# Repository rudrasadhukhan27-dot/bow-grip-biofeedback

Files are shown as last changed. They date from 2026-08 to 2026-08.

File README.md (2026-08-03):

# Bow-Grip Biofeedback: An Open Wearable for Measuring Violin Bow-Hold Tension


An open-source wearable that continuously measures violin bow-grip force, forearm muscle activation, and bow motion, and can deliver real-time haptic feedback when grip exceeds a personalised threshold. Built around an ESP32 and off-the-shelf sensors for roughly ₹4,000 / ~US$50 in parts.

This repository contains the complete hardware design, firmware, logging software, experimental protocol, pre-registration, analysis code, and results of a 33-session single-subject study conducted with the device.

The wearable in playing position

---

## Why this exists

Excessive bow-hold tension ("overgrip") is a widely discussed contributor to playing-related pain and injury among string players, but it is usually assessed by a teacher's eye rather than measured. This project asks whether it can be measured continuously and unobtrusively during real playing, whether haptic feedback reduces it, and whether it can be predicted before it occurs.

The study answers the first question clearly, the second one negatively, and the third one partially. All three results are reported here.

---

## Key findings (summary)

Across 33 playing sessions by a single violinist, in a pre-registered A-B-A-B reversal design with a transfer test:

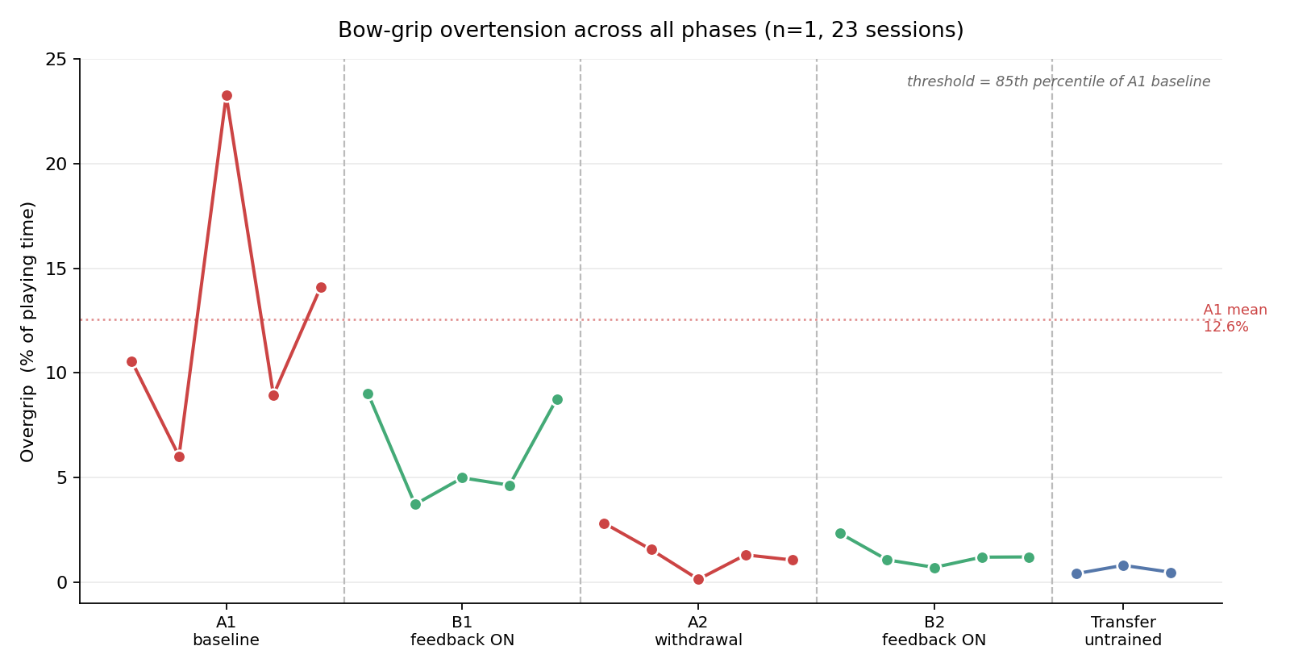
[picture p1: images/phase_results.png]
Overgrip across all phases


| Phase | Haptic feedback | Overgrip (% of playing time) |
|---|---|---|
| A1 baseline | off | **12.6%** |
| B1 intervention | on | 6.2% |
| A2 withdrawal | off | 1.4% |
| B2 re-intervention | on | 1.3% |
| Transfer (untrained repertoire) | off | **0.6%** |

**1. Overgrip fell by roughly 95% and stayed down.** Baseline versus withdrawal, re-intervention, and transfer all show complete non-overlap (NAP = 100%, Tau = +1.00). The reduction persisted with feedback removed and generalised to repertoire the device had never been used with. Note that each phase was recorded within a single day, so these are **descriptive** comparisons across 5 testing days, not inferentially tested replicates — see [`docs/DEVIATIONS.md`](docs/DEVIATIONS.md).

**2. The design did not show that the haptic feedback caused it.** Overgrip declined monotonically with elapsed time (*r* = −0.858, *p* = 1.7 × 10⁻⁷). Adding feedback on/off to the trend model explained nothing (*p* = 0.77), and the first feedback phase was not distinguishable from baseline. A 14-day unmeasured gap between B1 and A2 contains the largest single drop (6.2% → 1.4%). Practice, measurement reactivity, proprioceptive attention from wearing the sensor, and unrecorded activity during that gap are all equally consistent with the data. **This is reported as a null result on the causal question.**

**3. Overgrip onset is weakly predictable.** A gradient-boosted model using leave-one-session-out validation reaches average precision 0.093 at the pre-registered 200–400 ms horizon — about 7× chance and 2× a grip-level baseline (ROC-AUC 0.86). But performance degrades sharply beyond 200 ms, the predictive signal comes almost entirely from grip dynamics rather than bow kinematics, and at a tolerable false-alarm rate (≤2/min) event recall is poor. Practical warning systems are not yet viable from these signals.

Full details in [`RESULTS.md`](RESULTS.md).

---

## Hardware

Electronics in the printed enclosure
EMG electrode placement on the forearm extensors

### Bill of materials

| Component | Notes |
|---|---|
| ESP32-WROOM-DA dev board | Any ESP32 with ADC1 pins available |
| Force-sensitive resistor (FSR) | Mounted at the thumb contact point on the bow |
| BioAmp EXG Pill (Upside Down Labs) | Surface EMG front-end; powered from **3.3 V** |
| MPU-6050 IMU | I²C, address `0x68` |
| ERM coin vibration motor, 3 V, ~10 mm | ~60–100 mA |
| IRLZ44N logic-level MOSFET | Motor driver |
| 1N4007 diode | Flyback across motor |
| Resistors | Gate resistor; FSR voltage divider |
| Gel electrodes (×3) | Disposable, for EMG |
| 3D-printed enclosure | STLs in [`hardware/`](hardware/) |

### Pin map

| Signal | ESP32 pin |
|---|---|
| FSR (thumb) | D35 |
| FSR (second channel, unused) | D34 |
| EMG output (BioAmp) | D32 |
| IMU SDA | D21 |
| IMU SCL | D22 |
| Motor gate (MOSFET) | D25 |

All analog inputs are on ADC1, which remains usable while WiFi/Bluetooth is active.

**Important:** power the BioAmp EXG Pill from the **3.3 V** rail, not 5 V. At a 3.3 V supply its output cannot exceed the ESP32's ADC range, so no level shifting or divider is required.

### Electrode placement

Two signal electrodes (IN+, IN−) on the belly of the forearm **extensor** group — the hairy, dorsal side of the bowing forearm, roughly one third of the way from elbow to wrist — spaced 2–3 cm apart along the muscle fibres. Reference electrode on a bony landmark (olecranon or wrist). Clean the skin with alcohol and mark the positions so placement is repeatable across sessions.

### Enclosure

`hardware/electronics_box_snap.stl` and `electronics_lid_snap.stl`: an 86 × 56 × 29 mm snap-fit case with 26 mm internal depth, a front window with a 3 mm frame, and two side cable slits. Print the lid plate-down for a support-free surface. Snap engagement is 0.8 mm — reduce to 0.5 mm if your printer runs tight or you print in brittle PLA.

---

## Firmware

[`firmware/logger_firmware.ino`](firmware/) samples all channels on a fixed schedule and streams CSV over USB serial at 115200 baud.

```
t_ms,fsr1,fsr2,emg,ax,ay,az,gx,gy,gz,mode
```

Two modes, switched by sending a single character over serial:

- `R` — **record**: motor disabled. Used for all baseline, withdrawal, and transfer sessions.
- `F` — **feedback**: motor driven by a two-zone ramp above the grip threshold.

The feedback curve is defined by `GRIP_THRESH` and `ZONE2_START`. **These must be derived from the individual's own baseline data, not copied from this repository.** In this study they were set to the 85th and 95th percentiles of the participant's pooled A1 grip distribution (1301 and 1584 in raw ADC units).

Dependencies: `Wire`, [`MPU6050_tockn`](https://github.com/tockn/MPU6050_tockn). The tockn library is used because many inexpensive MPU-6050 modules are clones that fail to initialise with Adafruit's driver. Note that it reports acceleration in **g**, not m/s².

The firmware targets 100 Hz. Achieved rates ranged from 21 Hz to 100 Hz depending on I²C timing; the effective rate is recoverable per session from the `t_ms` column and should be reported rather than assumed.

ESP32 Arduino core 3.x is required — the code uses `ledcAttach(pin, freq, res)` and pin-addressed `ledcWrite`, which replaced the older `ledcSetup`/`ledcAttachPin` API.

---

## Logging software

[`software/logger.py`](software/) reads the serial stream and writes one CSV per session, validating every row and reporting a live corruption rate.

```bash
pip install pyserial

# baseline / withdrawal / transfer session (motor off)
python3 logger.py S1_A1_s01.csv

# feedback session (motor on)
python3 logger.py S1_B1_s01.csv --mode F
```

Rows are rejected unless they contain exactly 11 fields with correctly typed values and a mode flag of exactly `R` or `F`. This matters: at 230400 baud this build produced intermittently garbled rows, with the mode column bleeding into adjacent values. Dropping to 115200 eliminated the corruption (0.00% rejection in all subsequent sessions), and strict validation catches anything that still slips through.

---

## Experimental protocol

[`docs/data_collection_protocol.md`](docs/) contains the full session procedure. In brief, each session ran:

1. Fixed warm-up (before logging)
2. 3 × 5 s maximum voluntary contractions (MVC), for per-session EMG normalisation
3. 30 s rest baseline holding the instrument
4. 3 × maximum grip presses (pre)
5. ~8 minutes of fixed repertoire — A minor harmonic and D major, three octaves, cycled continuously at fixed tempo and dynamic
6. 3 × maximum grip presses (post)
7. Borg CR-10 and 0–10 discomfort ratings

Held constant across all sessions: repertoire, tempo, dynamic level, time of day, warm-up, electrode positions, sensor mounting, **and bow**. Dynamic level matters particularly — if loudness varies, force spikes required by the music become indistinguishable from overgrip.

The pre-registration, written and locked before data collection, is in [`docs/pre_registration.md`](docs/).

---

## Analysis

[`analysis/`](analysis/) contains the prediction pipeline:

- `predict.py` — resampling to a uniform 50 Hz grid, IMU-based segmentation of the bowing period, overgrip onset detection, and 21-feature extraction
- `eval.py` — leave-one-session-out validation with event-level recall at a bounded false-alarm rate, plus permutation feature importance
- `lead.py` — the lead-time curve across anticipation horizons

One methodological note worth repeating: the primary outcome is the percentage of **playing** time above threshold. Early analyses that used whole-file data were inflated by the MVC clenches and maximum grip presses, which are deliberate maximal squeezes. The bowing period is segmented from IMU motion before computing the outcome.

---

## Limitations

- **Single subject.** All findings are within-individual. Nothing here establishes generality across violinists.
- **Sessions are clustered by day.** All 33 sessions fall on 7 calendar dates, with each phase run as five consecutive recordings in a single sitting. Sessions within a phase are therefore not independent observations, phase is confounded with date, and the reported effect-size statistics are optimistic. See `RESULTS.md` §8.
- **Practice and intervention are confounded.** The reversal design failed to isolate the feedback; see finding 2 above.
- **Phase is confounded with day, and sessions are pseudo-replicated.** All sessions in a phase were recorded in one afternoon minutes apart, giving 5 testing days rather than 23 independent sessions. Inferential statistics on phase comparisons are not appropriate; the comparisons are descriptive.
- **A 14-day unmeasured interval** sits between B1 and A2, spanning the largest observed change.
- **Subjective secondary outcomes were not collected.** Borg CR-10 and discomfort ratings were pre-registered but never recorded, and no session log was kept.
- **Floor censoring.** The FSR cannot distinguish very light contact from no contact — both read zero. As grip lightened over the study, an increasing share of playing fell below the sensor's activation floor (up to 57% of samples in the final session). This does not affect the overgrip metric, which counts samples above a high threshold, but median and mean grip in later sessions should be read as directional only. A fresh-sensor comparison confirmed the original FSR's low-force sensitivity had **not** degraded, ruling out sensor wear as the explanation.
- **EMG is not comparable across an electrode-setup change** partway through the study. Activation declined within each setup era, but absolute levels either side of the boundary cannot be compared.
- **One discarded run.** Five sessions were invalidated by using a different bow, which altered thumb contact geometry enough to change the grip distribution substantially. Those sessions are retained in the trend analysis as practice exposure but excluded from phase comparisons.
- **Threshold provenance.** The overgrip threshold was derived from A1 and held fixed thereafter by design, meaning later phases were scored against an early-study reference.
- **No blinding.** The participant knew which condition each session was in.

---

## What would strengthen this

The single most valuable extension is a three-arm design with additional participants: practice-only (no device), device-worn-but-inert, and device-with-feedback. That would separate motor practice, measurement reactivity, and haptic feedback — the three explanations this study cannot currently distinguish.

---

## Repository structure

```
firmware/     ESP32 Arduino sketches (logging + feedback, bench tests)
software/     Python serial logger
hardware/     Enclosure STLs, pin map, wiring notes
docs/         Pre-registration, deviations, protocol, build guide
analysis/     Prediction pipeline and validation scripts
data/         Session CSVs, incl. excluded runs (see data/README.md)
```

---

## Licence

- Code (`firmware/`, `software/`, `analysis/`): [MIT](LICENSE)
- Hardware designs (`hardware/`): CERN-OHL-P v2
- Documentation, protocol, and results (`docs/`, `README.md`, `RESULTS.md`): CC BY 4.0

---

## Credits

This project builds on the **BioAmp EXG Pill** by [Upside Down Labs](https://github.com/upsidedownlabs), an open-source biopotential front-end. Please observe their licence terms when reusing that portion of the design.

IMU support uses [MPU6050_tockn](https://github.com/tockn/MPU6050_tockn) by tockn.

---

## Citing this work

See [`CITATION.cff`](CITATION.cff), or use the DOI issued by Zenodo for the corresponding release.

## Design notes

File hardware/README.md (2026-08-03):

# Hardware

## Pin map

| Signal | ESP32 pin | Notes |
|---|---|---|
| FSR (thumb) | D35 | Voltage divider to GND; primary grip signal |
| FSR (second) | D34 | Unused in this build |
| EMG output | D32 | BioAmp EXG Pill, powered from **3.3 V** |
| IMU SDA | D21 | MPU-6050 at `0x68` |
| IMU SCL | D22 | |
| Motor gate | D25 | IRLZ44N gate via series resistor |

All analog inputs are on ADC1, which stays usable while the radio is active.

## Notes that cost time to learn

- **Power the BioAmp from 3.3 V, not 5 V.** At a 3.3 V supply its output cannot exceed the ESP32's ADC range, so no divider or level shifter is needed.
- **The motor needs a flyback diode** (1N4007) across its terminals and a logic-level MOSFET. Without the diode, switching spikes couple into everything.
- **Battery feeds VIN**, never the 3V3 pin — the 3V3 pin bypasses the regulator.
- **Many MPU-6050 modules are clones** that fail to initialise with some libraries even when an I²C scan finds them at `0x68`. `MPU6050_tockn` works; note it reports acceleration in g.
- **Sensor placement matters more than sensor count.** A second FSR on the middle finger recorded almost nothing — that finger applies negligible force in a violin bow hold. Thumb and index are the pressure points.
- **The bow is part of the calibration.** Changing to a different bow altered thumb contact geometry enough to shift the grip distribution substantially and invalidated a five-session run. Treat the instrument as a fixed experimental condition.

## Enclosure

`electronics_box_snap.stl` + `electronics_lid_snap.stl` — 86 × 56 × 29 mm snap-fit case, 26 mm internal depth, 2 mm walls, 3 mm floor. Front window with a 3 mm frame; two 18 × 10 mm side slits for cabling, one offset 15 mm toward the front.

Print the lid plate-down (lip upward) for a support-free top surface. Snap engagement is 0.8 mm with 0.3 mm lip clearance per side — reduce engagement to ~0.5 mm if the lid will not seat or if printing in brittle PLA, increase to ~1.0 mm if it is loose.

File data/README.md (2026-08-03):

# Session data

33 playing sessions from a single participant. 23 in this directory were used for phase comparisons; 10 in [`excluded/`](excluded/) were discarded for documented reasons but are published because they still represent real practice exposure and are used in the trend analysis.

## Files

| Pattern | Phase | Feedback | n |
|---|---|---|---|
| `S1_A1_s01–05.csv` | A1 baseline | off | 5 |
| `S1_B1_s01–05.csv` | B1 intervention | on | 5 |
| `S1_A2_s01–05.csv` | A2 withdrawal | off | 5 |
| `S1_B2_s01–05.csv` | B2 re-intervention | on | 5 |
| `S1_TR_s01–03.csv` | Transfer, untrained repertoire | off | 3 |

Transfer sessions used a different piece each: s01 Albinoni *Allegro assai* (bars 1–20, played slower than the other two), s02 Mel Bonis *Allegretto non troppo* (bars 1–20), s03 Florence Price *Elfentanz* (bars 1–38).

### Excluded

| Pattern | Reason |
|---|---|
| `excluded/S1_A2_attempt1_noEMG_s01–05.csv` | EMG electrodes were not applied. Grip data valid; EMG channel meaningless. |
| `excluded/S1_A2_attempt2_differentbow_s01–05.csv` | A different bow altered thumb contact geometry enough to shift the grip distribution. |

Both are retained in the practice-exposure trend analysis. Neither is used for phase comparisons. See [`../docs/DEVIATIONS.md`](../docs/DEVIATIONS.md).

## Columns

| Column | Meaning |
|---|---|
| `wallclock_iso` | **Cleared.** Host timestamps removed before publication; column retained so field positions match the analysis code. |
| `t_ms` | Device millisecond timestamp — use this for all timing |
| `fsr1` | Thumb force, raw ADC 0–4095 |
| `fsr2` | Second FSR channel — not a signal, see below |
| `emg` | BioAmp EXG Pill output, raw ADC 0–4095, DC-centred |
| `ax, ay, az` | Accelerometer, g |
| `gx, gy, gz` | Gyroscope, deg/s |
| `mode` | `R` motor off, `F` feedback active |

## Before you analyse

- **Use `t_ms`, not row index.** Effective sample rate varies: roughly 21–50 Hz for A1 and B1, a stable 100 Hz from A2 onward after a serial baud fix. Recover it per file.
- **Segment the bowing period first.** Each file begins with MVC clenches, a rest baseline, and maximum grip presses — deliberate maximal squeezes that will inflate any whole-file statistic. The published analysis isolates bowing via gyroscope magnitude (2 s rolling mean above 25 °/s, longest contiguous block). See [`../analysis/predict.py`](../analysis/predict.py).
- **`fsr2` is not a signal.** The second sensor sat on the middle finger, which applies negligible force in a violin bow hold. It was removed early on. Grip means thumb contact force.
- **Grip is floor-censored.** Very light contact and no contact both read 0. This affects median and mean grip in later sessions; it does not affect the overgrip metric, which counts samples above 1301.
- **EMG is an amplitude measure**, not a spectral one — the sample rate is far too low for median-frequency fatigue analysis.
- **EMG is not comparable across the electrode re-application** between B1 and A2. Absolute levels shift roughly threefold at that boundary.

## Overgrip threshold

1301 raw ADC — the 85th percentile of the pooled A1 baseline grip distribution (n = 70,025). Derived once from baseline and held fixed for every later phase, as pre-registered.

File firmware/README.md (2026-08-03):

# Firmware

| Sketch | Purpose |
|---|---|
| `logger_firmware.ino` | Main firmware. Streams CSV at 115200 baud; `R`/`F` switches record/feedback. |
| `sensor_check.ino` | Bench test. Verifies FSR, EMG, IMU, and motor; flags common FSR fault signatures. |

## Before collecting data

Run `sensor_check.ino` and confirm:

- **FSR** — steady baseline when untouched, smooth rise when pressed. Values jumping between 0 and 4095 indicate a loose connection or a missing divider resistor, not real force.
- **EMG** — mid-range value that moves when you clench. A flat trace usually means electrode contact, not wiring.
- **IMU** — roughly 1 g total acceleration at rest; gyroscope responds to rotation.
- **Motor** — audible and palpable buzz. Watch for a board brownout when it starts; if the sketch restarts, the motor's current draw is sagging the supply rail.

## Setting the feedback threshold

`GRIP_THRESH` and `ZONE2_START` in `logger_firmware.ino` must come from the wearer's own baseline. Collect the baseline phase with the motor off, pool the grip samples, and take the 85th and 95th percentiles. A guessed threshold either fires constantly or never.

## Requirements

- ESP32 Arduino core **3.x** — the sketches use `ledcAttach(pin, freq, res)` and pin-addressed `ledcWrite`, which replaced `ledcSetup`/`ledcAttachPin`
- [MPU6050_tockn](https://github.com/tockn/MPU6050_tockn)

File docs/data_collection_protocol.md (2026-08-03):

# Data Collection Protocol — Bow-Grip Study (1 + B)

This is the complete, do-it-in-order guide from "device built" to "data ready to analyze." It covers what to collect, how, the exact session steps, the study sequence, and the mistakes that silently ruin a dataset. Everything you need is here, including the logging firmware and laptop logger (the two pieces not yet built).

---

## 0. What you are collecting and why (read once)

**The recorded signal (continuous, every session):** force from both FSRs, EMG from the forearm, and motion from the IMU — all timestamped at 100 Hz. From this one stream you get *both* halves of the project:
- **B (prediction):** can overgrip be forecast ~200–300 ms before it happens, from grip + motion? (analyzed offline later)
- **Option 1 (causation):** does feedback produce a *lasting* drop in overgrip? (proven by the A-B-A-B sequence)

**The single most important rule:** during RECORD sessions the motor is OFF. You collect clean data motor-off; the motor only runs in the FEEDBACK phases. EMG is microvolt-level and the motor pollutes it, so never record clean data with it buzzing.

---

## 1. One-time prerequisites (do all of these before session 1)

### 1.1 Hardware verified
All three sensor types respond (already done): FSR1 (D35), FSR2 (D34), EMG (D32), IMU (0x68 on D21/D22). Motor on D25 buzzes.

### 1.2 Flash the logging firmware
This replaces the test sketch. It samples at 100 Hz, streams CSV over USB serial, and has a RECORD/FEEDBACK mode (motor off vs on). The motor curve bug is fixed here. **Full code in Appendix A.**

### 1.3 Set up the laptop logger
A short Python script reads the serial stream and writes a timestamped CSV file per session. **Full code in Appendix B.** Test it: run it, confirm a CSV fills with rows, open it, check all 10 columns have sensible numbers.

### 1.4 Calibrate the FSRs to real force units (do once)
ADC counts aren't publishable; convert them to grams-force. **Procedure in Appendix C.** Save the calibration curve — you apply it later in analysis, not on the device.

### 1.5 Lock your pre-registration (write it BEFORE collecting)
Decide and write down, and do not change once data starts:
- **Hypothesis** (e.g., "feedback reduces overgrip rate, and the reduction persists when feedback is removed").
- **Primary outcome metric** — pick ONE now. Recommended: **overgrip rate = % of playing time grip exceeds your personal overgrip threshold.** (Alternatives: overgrip events per minute; % of bow changes that are overgrip events.)
- **Overgrip threshold definition** — e.g., grip force above the 85th percentile of your own relaxed-baseline playing, in calibrated grams. Define the rule, not the number (the number comes from baseline data).
- **Phase structure and session counts** (Section 4).
- **Repertoire, tempo, dynamics** held constant (Section 1.6).

### 1.6 Fix the experimental conditions (these stay identical every session)
Variability here masks the effect you're hunting, so nail them down:
- **Repertoire:** the same one or two etudes/scales every session. Pick material with frequent bow changes (where overgrip lives).
- **Tempo:** fixed BPM with a metronome. Same every session.
- **Dynamics:** same dynamic level (e.g., mezzo-forte) throughout. This is critical — it removes the "loud notes legitimately need force" confound, so a force spike means overgrip, not music.
- **Time of day:** same window each day (fatigue and warmth vary across the day).
- **Warm-up:** a fixed, identical warm-up before every recording.
- **Electrode placement template:** mark the electrode spots (photo + measure from a bony landmark) so EMG placement is repeatable. Placement drift changes EMG amplitude between sessions.

### 1.7 Consent/ethics (if anyone other than you participates)
Written informed consent; parental consent for under-18s. Check your school's human-subjects process — required before collecting from others and for competitions like ISEF.

---

## 2. The data you collect (exact contents)

### 2.1 Continuous stream (logged automatically, 100 Hz)
Each CSV row: `wallclock_iso, t_ms, fsr1, fsr2, emg, ax, ay, az, gx, gy, gz, mode`
- `t_ms` device timestamp (keeps all channels aligned — this is your sync).
- `fsr1, fsr2` raw 0–4095 (convert to grams later via calibration).
- `emg` raw 0–4095.
- `ax,ay,az` accel (g), `gx,gy,gz` gyro (deg/s) — bow motion.
- `mode` R or F.

### 2.2 Per-session metadata (write in the session log, Appendix D)
Subject ID, date, **time of day**, **phase** (A1/B1/A2/B2/Transfer), **condition** (motor OFF or ON), repertoire, tempo (BPM), dynamic level, warm-up done (y/n), electrode placement OK (y/n), battery charged (y/n), any anomalies (slips, interruptions, motor accidentally on, etc.), file name.

### 2.3 Per-session calibration recordings (short, every session)
- **MVC (max voluntary contraction):** 3 × 5-second maximum forearm clenches at the start. Used to normalize EMG so it's comparable across sessions (electrode placement varies day to day — without this, EMG amplitudes aren't comparable). Log the file/time markers.
- **Rest baseline:** 30 s of quiet (instrument held, not playing) to capture resting grip/EMG.

### 2.4 Optional secondary outcomes (recommended, low effort)
- **Grip endurance / strength:** squeeze the digital dynamometer (peak-hold) before and after the session; the drop is a fatigue biomarker. (You can drop this once you've validated EMG-based fatigue against it — see Section 6.)
- **Subjective:** Borg CR-10 perceived exertion and a 0–10 forearm discomfort rating, immediately post-session.

---

## 3. Single-session procedure (run this exact sequence every time)

1. **Setup (5 min):** charge confirmed, device on, electrodes placed per template (clean skin first), glove/FSRs on, IMU seated on hand. Start the logger on the laptop with a new filename (Section 7 naming).
2. **Confirm signals (1 min):** wiggle bow → IMU moves; clench → EMG moves; press fingers → FSRs move. Abort and fix if any channel is dead.
3. **MVC recording (1 min):** mode = RECORD. Record 3 × 5 s maximum clenches, ~10 s rest between. Note the times.
4. **Rest baseline (1 min):** hold instrument quietly, 30 s, no playing.
5. **Pre-session measures:** dynamometer max (×3, record peak); note nothing hurts.
6. **Fixed warm-up:** identical every session.
7. **The recording (the data):** mode per the phase (RECORD = motor off for A-phases; FEEDBACK = motor on for B-phases). Play the fixed repertoire at the fixed tempo and dynamic for a fixed duration (e.g., 8–12 min). Keep the logger running the whole time.
8. **Post-session measures:** dynamometer max (×3), Borg CR-10, discomfort rating.
9. **Stop & save:** stop logger, confirm the CSV saved and has rows, back it up immediately (Section 7).
10. **Fill the session log** (Appendix D) completely before you forget.

Keep every session the same length and structure. Your statistical power comes from many comparable sessions, not from any one long one.

---

## 4. The study sequence (the A-B-A-B reversal)

Run phases in order. **Each phase = 5–8 sessions** (minimum 3; 5+ is much safer). Same repertoire/tempo/dynamics throughout all phases.

| Phase | Mode | Motor | Purpose |
|---|---|---|---|
| **A1 baseline** | RECORD | OFF | your natural overgrip rate |
| **B1 intervention** | FEEDBACK | ON | does overgrip drop while feedback is on? |
| **A2 withdrawal** | RECORD | OFF | **the key phase** — does the drop persist with feedback gone? |
| **B2 re-intervention** | FEEDBACK | ON | does the effect return, confirming feedback caused it? |
| **Transfer test** | RECORD | OFF | play *untrained* repertoire — did the improvement carry over? |

**The logic:** a drop in B1 alone proves nothing. A drop that **persists into A2** = learning. A pattern that tracks feedback on/off/on/off across all phases = causal evidence from one subject. The transfer test at the end (music the device never trained on) is what shows the skill actually changed, not just task-specific correction.

**If you have 1–2 other violinists:** run the same sequence on each (they can do fewer sessions). Your own deep run is the spine; they are replication. A busy participant who can only do 1–2 sessions is a "generalization probe," not a full subject — use their data descriptively, don't force it into the reversal.

---

## 5. The prediction (B) data — what to ensure during collection

B is analyzed offline from the same recordings, so you don't do anything special on the device. But make sure the **A1 baseline (motor-off) sessions contain plenty of natural overgrip events** — that's the raw material for training the predictor. Practically: the baseline material should provoke overgrip (frequent bow changes, your normal playing). You need many events across several baseline sessions for the offline model to learn from. Nothing to configure — just don't skimp on baseline sessions.

---

## 6. Validate EMG-based fatigue early (do this in the first 2–3 sessions)

Record both the dynamometer drop and the EMG. Later you'll check offline whether the EMG fatigue signal (its frequency content shifting down over a session) tracks the grip-strength drop. Once they agree, you can rely on EMG alone and stop the per-session dynamometer step. Do this validation early so you're not stuck doing manual grip tests forever.

---

## 7. Data management (do this rigorously — lost/mislabeled data is unrecoverable)

- **File naming:** `S1_A1_s03_2026-07-14.csv` = subject S1, phase A1, session 03, date. Be consistent.
- **One folder per subject;** a master spreadsheet (the session log) with one row per session.
- **Back up after every session** — copy the CSV to a second location (cloud + drive). A corrupted laptop mid-study with no backups ends the project.
- **Never edit raw CSVs.** Do all cleaning in analysis scripts on copies.
- Keep the **MVC and rest-baseline timestamps** in the log so you can find them in each file.

---

## 8. Quality control & pitfalls (the things that quietly ruin datasets)

**Every session, check:**
- Motor is OFF during RECORD phases (verify — a stray buzz pollutes EMG).
- All channels live before recording (no dead/railed sensor).
- Electrodes on the marked spots; skin cleaned.
- Battery charged (brownouts corrupt data).
- Logger actually wrote rows (open the file).

**Confounds to control (these mimic or hide the effect):**
- **Practice effect:** you improve just from repetition. The A-B-A-B reversal is your defense — only feedback-linked changes (appearing/disappearing with the motor) count as the effect.
- **Fatigue / time of day:** same time window, fixed session length.
- **Dynamics drift:** hold the dynamic level constant, or loud passages get mislabeled as overgrip.
- **Electrode drift:** same placement every time (template + MVC normalization).
- **Placebo/expectation:** be aware you know when feedback is on; report it as a limitation.

**Do NOT:**
- Change the threshold, repertoire, tempo, or electrode position mid-study.
- "Clean up" raw files by hand.
- Decide your outcome metric *after* seeing the data (that's fishing — lock it in pre-registration).
- Skip the withdrawal phase (A2) — it's the phase that proves learning.

---

## 9. What you'll have at the end

Per session: a 100 Hz CSV (force, EMG, motion), MVC + rest baselines, pre/post measures, and a complete metadata row. Across the A-B-A-B sequence plus transfer test, that's enough to (a) build and validate the offline overgrip predictor [B], and (b) test whether feedback produced a lasting, causal reduction in overgrip [Option 1]. Analysis (feature extraction, leave-one-session-out validation, single-case statistics like Tau-U, calibration to grams, EMG fatigue) happens offline on these files.

---

# Appendix A — Logging firmware (flash this)

Samples 100 Hz, streams CSV over USB serial, RECORD/FEEDBACK mode via serial command (`R` = record/motor-off, `F` = feedback/motor-on). Motor curve fixed (real two-zone ramp). Set baud to 230400 in your logger to match. Keep the board still at power-up (gyro calibration).

```cpp
#include <Wire.h>
#include <MPU6050_tockn.h>

const int FSR1_PIN=35, FSR2_PIN=34, EMG_PIN=32, SDA_PIN=21, SCL_PIN=22, MOTOR_PIN=25;
const int MOTOR_CH=0, MOTOR_FREQ=20000, MOTOR_RES=8;
MPU6050 mpu(Wire);
bool imuOK=false;
char mode='R';

// ---- feedback curve (set GRIP_THRESH/ZONE2_START from your calibration & baseline) ----
const int GRIP_THRESH=1600, ZONE2_START=2800;
const int MIN_MOTOR=60, ZONE1_MAX=110, MAX_MOTOR=220;
int gripToMotor(int g){
  if(g<=GRIP_THRESH) return 0;
  if(g<=ZONE2_START){ float t=(float)(g-GRIP_THRESH)/(ZONE2_START-GRIP_THRESH);
    return (int)(MIN_MOTOR + t*(ZONE1_MAX-MIN_MOTOR)); }
  float t=(float)(g-ZONE2_START)/(4095-ZONE2_START);
  int d=(int)(ZONE1_MAX + t*(MAX_MOTOR-ZONE1_MAX));
  return d>MAX_MOTOR?MAX_MOTOR:d;
}

unsigned long lastSample=0;
const unsigned long SAMPLE_US=10000;  // 100 Hz

void setup(){
  Serial.begin(230400);
  analogReadResolution(12);
  analogSetPinAttenuation(FSR1_PIN,ADC_11db);
  analogSetPinAttenuation(FSR2_PIN,ADC_11db);
  analogSetPinAttenuation(EMG_PIN,ADC_11db);
  ledcSetup(MOTOR_CH,MOTOR_FREQ,MOTOR_RES);
  ledcAttachPin(MOTOR_PIN,MOTOR_CH);
  ledcWrite(MOTOR_CH,0);
  Wire.begin(SDA_PIN,SCL_PIN);
  bool seen=false;
  for(byte a=1;a<127;a++){ Wire.beginTransmission(a); if(Wire.endTransmission()==0 && a==0x68) seen=true; }
  if(seen){ mpu.begin(); mpu.calcGyroOffsets(false); imuOK=true; }
  Serial.println("# t_ms,fsr1,fsr2,emg,ax,ay,az,gx,gy,gz,mode");
}

void loop(){
  if(Serial.available()){
    char c=Serial.read();
    if(c=='R'||c=='r'){ mode='R'; ledcWrite(MOTOR_CH,0); }
    if(c=='F'||c=='f'){ mode='F'; }
  }
  unsigned long now=micros();
  if(now-lastSample>=SAMPLE_US){
    lastSample+=SAMPLE_US;
    int f1=analogRead(FSR1_PIN), f2=analogRead(FSR2_PIN), e=analogRead(EMG_PIN);
    float ax=0,ay=0,az=0,gx=0,gy=0,gz=0;
    if(imuOK){ mpu.update();
      ax=mpu.getAccX(); ay=mpu.getAccY(); az=mpu.getAccZ();
      gx=mpu.getGyroX(); gy=mpu.getGyroY(); gz=mpu.getGyroZ(); }
    int grip = (f1>f2)?f1:f2;
    if(mode=='F') ledcWrite(MOTOR_CH, gripToMotor(grip)); else ledcWrite(MOTOR_CH,0);
    Serial.print(millis()); Serial.print(',');
    Serial.print(f1); Serial.print(','); Serial.print(f2); Serial.print(','); Serial.print(e); Serial.print(',');
    Serial.print(ax,3); Serial.print(','); Serial.print(ay,3); Serial.print(','); Serial.print(az,3); Serial.print(',');
    Serial.print(gx,2); Serial.print(','); Serial.print(gy,2); Serial.print(','); Serial.print(gz,2); Serial.print(',');
    Serial.println(mode);
  }
}
```

To switch modes during a session, send `R` or `F` from the serial monitor / logger. Default is RECORD.

---

# Appendix B — Laptop logger (Python)

Install once: `pip install pyserial`. Find your port (Arduino IDE shows it, e.g. `/dev/cu.usbserial-0001` on Mac, `COM5` on Windows). Run: `python logger.py S1_A1_s01_2026-07-14.csv`

```python
import serial, csv, time, sys

PORT = '/dev/cu.usbserial-0001'   # <-- set your port
BAUD = 230400
fname = sys.argv[1] if len(sys.argv) > 1 else 'session.csv'

ser = serial.Serial(PORT, BAUD, timeout=1)
print('Logging to', fname, '— Ctrl+C to stop')
with open(fname, 'w', newline='') as fh:
    w = csv.writer(fh)
    w.writerow(['wallclock_iso','t_ms','fsr1','fsr2','emg','ax','ay','az','gx','gy','gz','mode'])
    n = 0
    try:
        while True:
            line = ser.readline().decode(errors='ignore').strip()
            if not line or line.startswith('#'):
                continue
            p = line.split(',')
            if len(p) != 11:
                continue
            w.writerow([time.strftime('%Y-%m-%dT%H:%M:%S'), *p])
            n += 1
            if n % 500 == 0:
                print(n, 'samples')
    except KeyboardInterrupt:
        print('Stopped.', n, 'samples saved to', fname)
```

To send `R`/`F` mode commands, you can use the Arduino Serial Monitor (close the logger first, since only one program can hold the port) — or send from a second tiny script. Simplest workflow: set the mode in the Serial Monitor, close it, then start the logger.

---

# Appendix C — FSR force calibration (do once)

Goal: map raw ADC → grams-force so your data is in real units.

1. Mount the FSR as it'll be used (on the glove fingertip pad).
2. Press it against a **digital kitchen/jewelry scale** through a small rigid flat cap (so force transfers evenly to the sensor).
3. At several force levels spanning light→hard (e.g., 50, 100, 200, 400, 700, 1000+ g), hold steady and record BOTH the scale reading (grams) and the firmware's ADC value for that FSR.
4. Take 6–8 points. Repeat for FSR1 and FSR2 separately (they differ).
5. In Python, fit a curve (ADC→grams) per sensor — a smooth monotonic fit (polynomial or piecewise/interpolation). Save the curves.
6. Apply these in analysis to convert all logged ADC to grams. Don't put this on the device; keep raw ADC in the CSV and convert offline (reversible, documented).

Note: FSRs are approximate (±10–20%) and drift; recalibrate occasionally and report this as a limitation.

---

# Appendix D — Session log sheet (one row per session)

| Field | Example |
|---|---|
| Subject ID | S1 |
| Date | 2026-07-14 |
| Time of day | 16:30 |
| Phase | A1 |
| Session # | 03 |
| Condition (motor) | OFF |
| Repertoire | Etude X + scale |
| Tempo (BPM) | 92 |
| Dynamic | mf |
| Warm-up done | y |
| MVC recorded (times) | 00:20, 00:35, 00:50 |
| Rest baseline (time) | 01:10 |
| Dynamometer pre (kg) | 38 / 38 / 37 |
| Dynamometer post (kg) | 34 / 35 / 34 |
| Borg CR-10 post | 4 |
| Discomfort 0–10 | 2 |
| Electrodes on template | y |
| Battery charged | y |
| File name | S1_A1_s03_2026-07-14.csv |
| Anomalies | none |

---

*Design note: this is a within-subject (n-of-1, optionally + a couple replications) study by intent. Its rigor comes from many comparable sessions and the reversal structure, not sample size — which is exactly why one well-run subject can carry it. Lock the conditions, keep every session identical, back up everything, and don't decide the outcome metric after seeing the data.*

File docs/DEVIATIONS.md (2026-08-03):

# Deviations from Pre-Registration

The pre-registration in [`pre_registration.md`](pre_registration.md) was locked on 07/07/2026 and has not been edited. Every difference between what was planned and what happened is recorded here.

---

## Threshold value (planned, resolved as specified)

The pre-registration fixed the *rule* — 85th percentile of the participant's own A1 baseline grip — and left the number to be derived. Pooling all five A1 sessions (n = 70,025 samples) gave **1301 raw ADC units**. Per-session A1 85th percentiles were 1215, 1284, 1424, 1171, 1339, a tight cluster indicating a stable baseline. This value was set in firmware before B1 and held constant for B1 and B2.

`ZONE2_START`, the point where the feedback ramp steepens, was set to the A1 95th percentile (1584). This parameter was not pre-specified; it affects only the shape of the haptic response, not the outcome measure.

**Units:** analysis was performed in raw ADC, which the pre-registration permits ("raw ADC if analyzed before calibration"). Force calibration to grams was not completed.

---

## Sessions per phase

Transfer test ran **3 sessions** rather than the planned 2. All other phases ran 5 as planned.

---

## Discarded and repeated runs

Three separate attempts were made at the A2 withdrawal phase. All were real playing sessions and are counted as practice exposure in the trend analysis; only the third is used for phase comparisons.

| Attempt | Sessions | Outcome |
|---|---|---|
| 1 | 5 | **Excluded.** EMG electrodes were not applied. Grip data is valid and retained for trend analysis; EMG is absent. |
| 2 | 5 | **Excluded.** A different bow was used, altering thumb contact geometry enough to shift the grip distribution substantially (elevated zero-fraction and elevated upper percentiles simultaneously). Retained for trend analysis only. |
| 3 | 5 | **Analysed.** Original bow, electrodes applied. |

Total playing sessions: **33**. Sessions used for phase comparisons: **23**.

---

## Controlled conditions — one omission discovered during the study

**The bow was not listed as a controlled condition** in section 7 of the pre-registration. It should have been. Changing bows between runs invalidated five sessions, as above. Subsequent sessions all used the original bow, and any replication should treat the instrument as a fixed experimental condition alongside repertoire, tempo, and dynamic level.

---

## Session scheduling — the most consequential deviation

The pre-registration did not specify spacing between sessions. In execution, **all sessions within a phase were recorded on a single day, 13–21 minutes apart.**

| Date | Phase | Sessions | Clock times |
|---|---|---|---|
| 08 Jul 2026 | A1 | 5 | 18:46, 19:00, 19:13, 22:51, 23:06 |
| 09 Jul 2026 | B1 | 5 | 17:31, 17:50, 18:03, 18:19, 18:34 |
| 23 Jul 2026 | A2 | 5 | 16:45, 17:06, 17:25, 17:41, 17:56 |
| 25 Jul 2026 | B2 | 5 | 17:53, 18:10, 18:31, 18:45, 19:00 |
| 28 Jul 2026 | Transfer | 3 | 17:11, 17:26, 17:44 |

(The two discarded A2 attempts were also recorded on 23 Jul, earlier in the same afternoon.)

Three consequences follow, and they are stated here rather than buried:

**1. Phase is perfectly confounded with day.** There are **5 distinct testing days, not 23 independent sessions.** No analysis can separate "which phase" from "which day."

**2. The reported inferential statistics are pseudo-replicated.** The Mann-Whitney tests in `RESULTS.md` treat five same-day recordings as independent replicates. They are not; they are consecutive recordings within one sitting. The nominal *p* values (0.004) therefore **overstate the strength of evidence**. Treated properly, the design yields one observation per condition, which cannot be tested inferentially. The phase comparisons should be read as **descriptive**, supported by complete non-overlap and effect magnitude, not as significance tests.

Partial mitigation: within-day trends are flat. Regressing log overgrip on within-day session order gives *p* > 0.2 for every day (A1 *p* = 0.61, B1 *p* = 0.87, A2 *p* = 0.92, B2 *p* = 0.42, TR *p* = 0.20). Improvement is not occurring within sittings, so the same-day sessions behave as repeated measurements of a stable daily state rather than as a within-day learning curve.

**3. A 14-day unmeasured gap sits inside the largest effect.** B1 ended 09 Jul; A2 began 23 Jul. Overgrip fell from 6.22% to 1.37% — a 78% relative reduction — across an interval in which nothing was recorded and ordinary violin practice presumably continued. This unmeasured period is the single most plausible driver of the study's headline reduction, and it further undermines any attribution to the haptic feedback.

Consistent with this, the decline fits elapsed calendar time better than session count (*r* = −0.858, *p* = 1.7 × 10⁻⁷ versus *r* = −0.809, *p* = 3.0 × 10⁻⁶ across the 23 analysed sessions), which is what a between-day consolidation process would predict and a within-session practice process would not.

**Any replication should space sessions across separate days**, one per day, with practice between sessions logged.

---

## Time of day

The pre-registration fixed session time at 17:00. A1 sessions 4 and 5 were recorded at **22:51 and 23:06**, following a 3.5-hour break after session 3. All other sessions fell between 16:45 and 19:00.

The two late sessions are the baseline phase, where fatigue or time-of-day effects would tend to *increase* measured overgrip and thus inflate the baseline against which all later phases are compared. Their values (6.02% and 16.69%) span the phase range and are not obvious outliers, but the deviation is noted.

---

## Secondary outcome substitutions

**Dynamometer replaced by FSR maximum grip press.** No hand dynamometer was available. Pre- and post-session grip strength was instead recorded as three maximum squeezes on the bow, captured by the thumb FSR. This is less precise than a dynamometer — contact geometry varies between repetitions and the sensor saturates above roughly 3300 ADC — so it is reported as an approximate fatigue index rather than a calibrated strength measure.

**Post-session grip presses were omitted in the A1 phase.** They were recorded from B1 onward. Pre/post fatigue comparison is therefore unavailable for A1.

**EMG spectral fatigue could not be computed.** The pre-registration specified median-frequency shift, which requires roughly 1000 Hz sampling. Achieved rates were 21–100 Hz, so EMG is reported as an amplitude/envelope measure only.

**Borg CR-10 and 0–10 discomfort ratings were not collected.** Section 6 of the pre-registration specified both as per-session secondary outcomes. Neither was recorded in any session, and no session log was kept. The subjective secondary outcomes are therefore entirely absent from this study.

---

## Sampling rate

The firmware targets 100 Hz. Achieved effective rates were **21–50 Hz for sessions 1–10** and a stable **100 Hz from session 11 onward**, after the serial baud rate was reduced from 230400 to 115200. The I²C IMU read is the limiting factor at the lower rates.

Grip and bow motion are low-frequency signals, so the outcome measure is not materially affected, but the rate is recovered per session from the `t_ms` column rather than assumed.

---

## Data corruption and its correction

At 230400 baud the serial stream produced intermittently malformed rows, most visibly the mode column bleeding into adjacent fields. Affected rows fail validation and are discarded by the logger.

From session 11 the baud rate was lowered to 115200 and row-level validation was tightened. Rejection rate thereafter was **0.00%** in every session.

---

## Analysis: playing-period segmentation

The pre-registered outcome is percentage of **playing** time above threshold. Early exploratory analyses computed this over whole files, which inflated the rate by including the MVC clenches and maximum grip presses — deliberate maximal squeezes performed before and after each recording.

The reported analysis segments the bowing period from IMU gyroscope magnitude (2 s rolling mean > 25 °/s, longest contiguous block) before computing the outcome. This is a refinement of the pre-registered procedure, not a change of measure; it removes contamination the pre-registration did not anticipate.

---

## Transfer test repertoire

The pre-registration specified untrained repertoire but did not name it in advance. Three different untrained pieces were used, one per session, rather than a single piece repeated:

| Session | Piece | Extent |
|---|---|---|
| TR s01 | Albinoni — *Allegro assai* | first 20 bars |
| TR s02 | Mel Bonis — *Allegretto non troppo* | first 20 bars |
| TR s03 | Florence Price — *Elfentanz* | first 38 bars |

Session 1 was played at a slower tempo than the other two. Because tempo affects bow-change frequency, and bow changes are where overgrip concentrates, transfer sessions are reported individually rather than pooled and the slower session is flagged in interpretation.

Using real repertoire rather than further scales makes this a stronger generalisation test than repeating a single untrained piece would have been, at the cost of the three sessions not being directly comparable to one another.

---

## Sensor configuration

**The second FSR was removed.** It was mounted on the middle finger, which applies negligible force in a violin bow hold, and recorded near-zero throughout A1. Grip is therefore **thumb contact force** from a single sensor. Firmware takes the stronger of the two FSR channels, so a single working sensor is functionally equivalent.

**Power source changed from battery to USB.** The lithium battery over-discharged to 0.7 V and was not replaced. All sessions ran on USB power via a tethered cable. This does not affect the signal but does constrain movement, and is noted as a practical limitation of the setup as tested.

---

## Confound status — H1 outcome

The pre-registration states that the practice effect is "addressed by the reversal design." **It was not adequately addressed.** The observed pattern was a monotonic decline across cumulative practice with no rebound on withdrawal, and feedback status contributed nothing beyond the trend (*p* = 0.77). H1 is reported as **not supported**: the study demonstrates a large durable reduction but cannot attribute it to the haptic feedback.

This is a limitation of the design as executed, and is stated as such in [`../RESULTS.md`](../RESULTS.md) rather than reframed.

---

## Session spacing — not as pre-registered in spirit

The pre-registration fixed a session time of day (5 pm) but did not specify spacing between sessions. In execution, all 33 sessions fell on **7 calendar dates**, with each phase's 5 sessions run consecutively within about 90 minutes on a single day:

| Date | Sessions | Phase |
|---|---|---|
| 2026-07-08 | 5 | A1 |
| 2026-07-09 | 5 | B1 |
| 2026-07-18 | 5 | A2 attempt 1 (excluded) |
| 2026-07-22 | 5 | A2 attempt 2 (excluded) |
| 2026-07-23 | 5 | A2 |
| 2026-07-25 | 5 | B2 |
| 2026-07-28 | 3 | Transfer |

Two consequences:

1. **Sessions within a phase are not independent observations.** Five consecutive 8-minute recordings separated by a few minutes each are closer to one long session than to five spaced ones. Effect-size statistics that treat sessions as independent (NAP, Tau, Mann-Whitney) are correspondingly optimistic, and the effective n per phase is nearer 1 than 5.

2. **Within-day fatigue is uncontrolled and works against the observed effect.** The pre-registration controlled fatigue by fixing session duration and time of day, which does not address five back-to-back sessions.

Phase is also perfectly confounded with date: every session in a phase shares a single day, so any day-specific factor — electrode placement that day, ambient temperature, how the participant felt — is indistinguishable from phase. A replication should space sessions across separate days.

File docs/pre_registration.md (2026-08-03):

# Pre-Registration — Bow-Grip Haptic Biofeedback Study

**Locked before data collection. Not modified after session 1.**

**Date locked:** 07/07/2026
**Investigator:** Rudra Sadhukhan

> Reproduced as locked. Everything that differed in execution is recorded separately in [`DEVIATIONS.md`](DEVIATIONS.md) rather than edited into this document.

---

## 1. Background & aim

An open, low-cost wearable measures violin bow-grip force (FSR), forearm muscle activation (EMG), and hand/bow motion (IMU). This study tests, within a single participant (with optional replication), whether haptic feedback reduces bow-grip overtension in a way that lasts, and whether overtension can be predicted before it occurs.

## 2. Hypotheses

- **H1 (primary, causal):** Haptic feedback reduces the overgrip rate during playing, and the reduction persists when feedback is removed (i.e. motor learning, not just real-time correction).
- **H2 (prediction):** Bow-grip overtension events can be predicted ~200–300 ms before onset from grip + motion signals, better than a force-rising baseline. (Analyzed offline.)

## 3. Design

Single-case experimental design, A-B-A-B reversal with a final transfer test, in one primary participant (S1). Optional 1–2 additional violinists as replication/generalization probes.

| Phase | Feedback (motor) | Sessions (planned) |
|---|---|---|
| A1 baseline | OFF | 5 |
| B1 intervention | ON | 5 |
| A2 withdrawal | OFF | 5 |
| B2 re-intervention | ON | 5 |
| Transfer test | OFF | 2 |

## 4. Primary outcome measure (locked)

**Overgrip rate** = percentage of playing time during which grip force exceeds the participant's personal overgrip threshold. Computed offline from the 100 Hz recording.

## 5. Overgrip threshold rule (locked now; number derived from A1 baseline)

Grip force above the **85th percentile** of the participant's own A1 relaxed-playing grip distribution (in calibrated grams-force; raw ADC if analyzed before calibration). The rule is fixed here; the numeric threshold is computed from A1 baseline data and then held constant for all later phases.

## 6. Secondary outcomes

- EMG-derived fatigue (downward shift of EMG median frequency across a session), normalized to per-session MVC.
- Grip-strength decline (dynamometer, pre vs post session) — used to validate the EMG fatigue metric early, then optional.
- Subjective: Borg CR-10 exertion; 0–10 forearm discomfort, post-session.

## 7. Controlled conditions (identical every session)

- **Repertoire:** A minor harmonic 3 octaves, D major 3 octaves
- **Tempo:** 76 BPM
- **Dynamic level:** mf
- **Time of day:** 5 pm
- **Fixed warm-up:** basic bowing drills for 5 min
- **Electrode placement:** per marked template (photo + landmark measurement)
- **Session recording duration:** 8 min

## 8. Signal & data collected

100 Hz stream: FSR1, FSR2, EMG, accel (x,y,z), gyro (x,y,z), timestamp, mode. Plus per session: 3×5 s MVC, 30 s rest baseline, pre/post dynamometer, Borg CR-10, discomfort, full metadata log.

## 9. Analysis plan (locked)

- **H1:** single-case analysis across phases — visual analysis (level/trend/overlap) plus a quantitative index (Tau-U or randomization test). Effect judged by whether overgrip rate drops in B phases and persists into A2, tracking feedback on/off across all four phases.
- **H2:** offline predictor (gradient-boosted trees on windowed features) trained/validated with leave-one-session-out cross-validation; report precision-recall (AUC-PR) and a lead-time curve; baseline to beat = "predict when force is already rising."
- **Transfer test:** compare overgrip rate on untrained repertoire vs baseline.

## 10. Confounds controlled

Practice effect (addressed by the reversal design), fatigue/time-of-day (fixed window + fixed duration), dynamics drift (held constant), electrode-placement drift (template + MVC normalization), expectation/placebo (acknowledged as a limitation).

## 11. Scope & limitations (stated in advance)

Findings are within-individual; generalization to violinists broadly is explicitly future work. "Overgrip" is an operational definition justified by held-constant dynamics, not a clinical label. Prediction accuracy expected to be modest and reported honestly against baselines.

## 12. Ethics

Self-experimentation for S1. Any additional participants: written informed consent (parental consent if under 18), per institutional human-subjects requirements, obtained before their data collection.

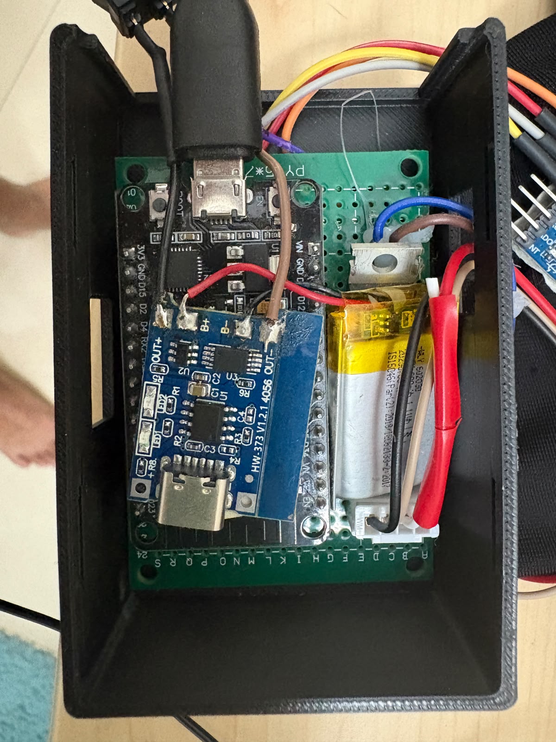
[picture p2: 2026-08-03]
images/electronics.jpeg

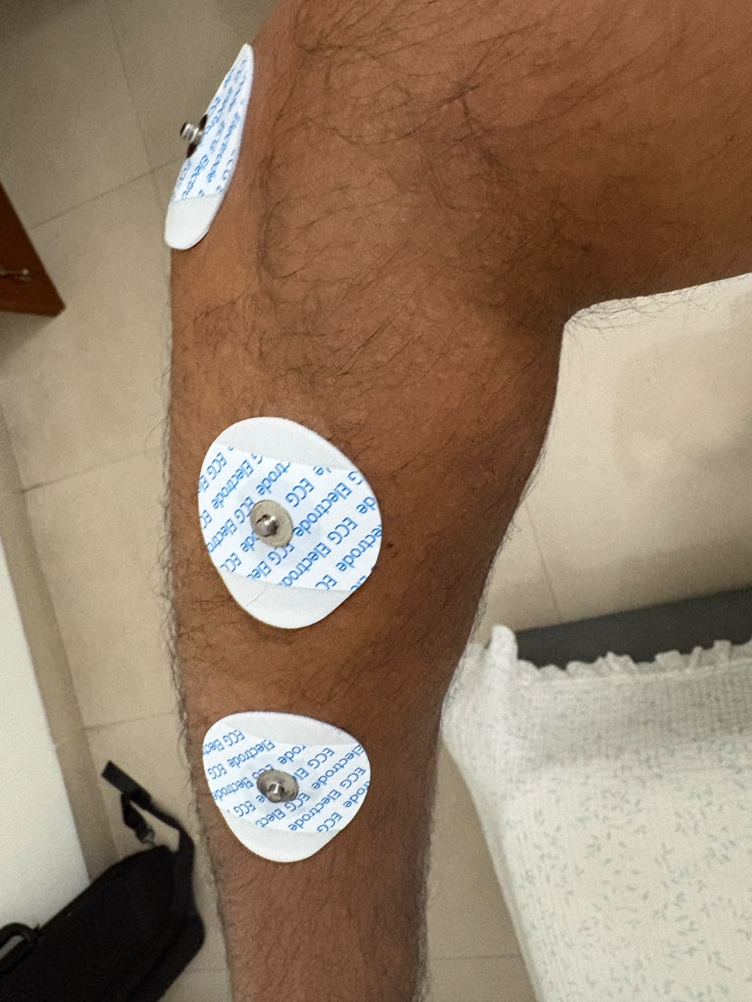
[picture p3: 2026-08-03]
images/electrodes.jpeg

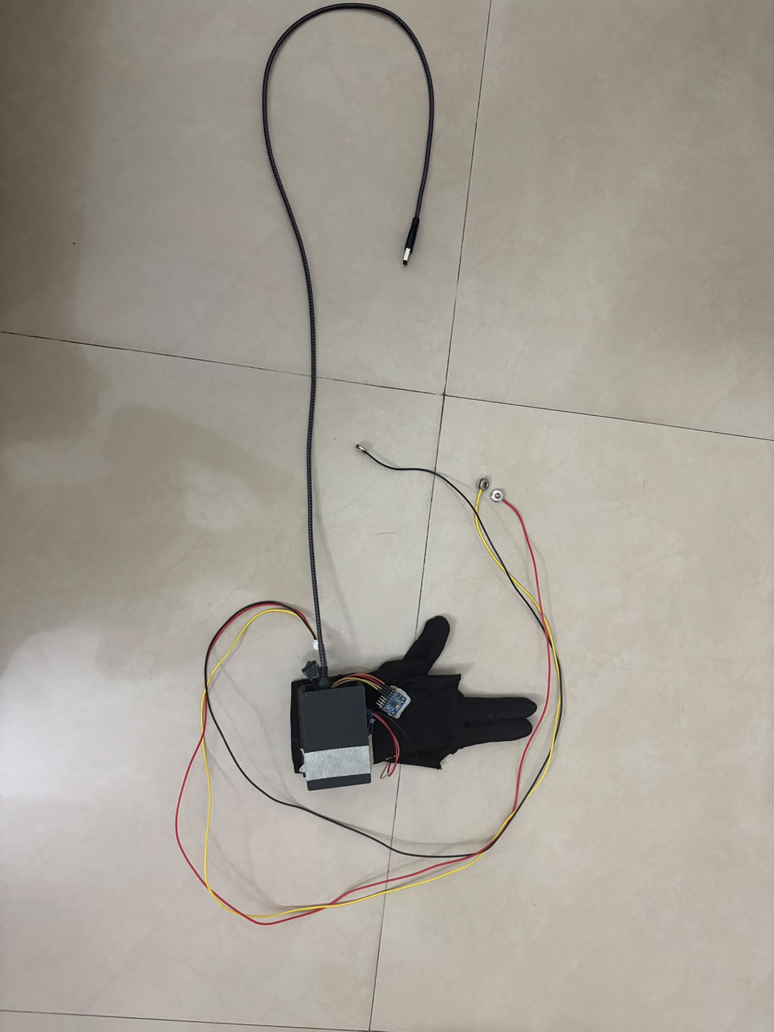
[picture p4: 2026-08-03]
images/kit.jpeg

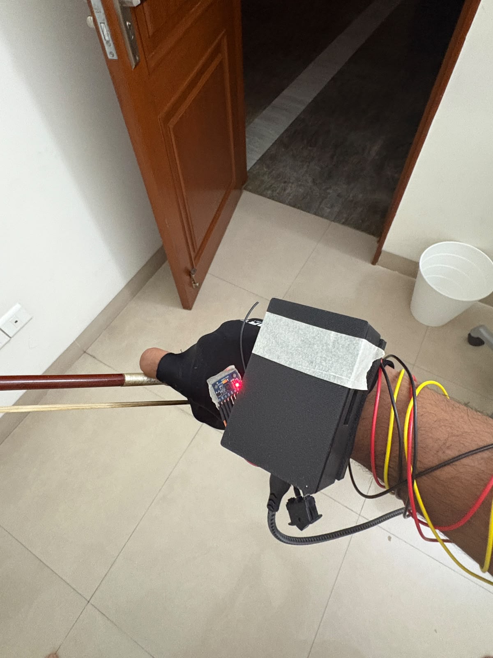
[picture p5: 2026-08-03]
images/device_in_hand.jpeg

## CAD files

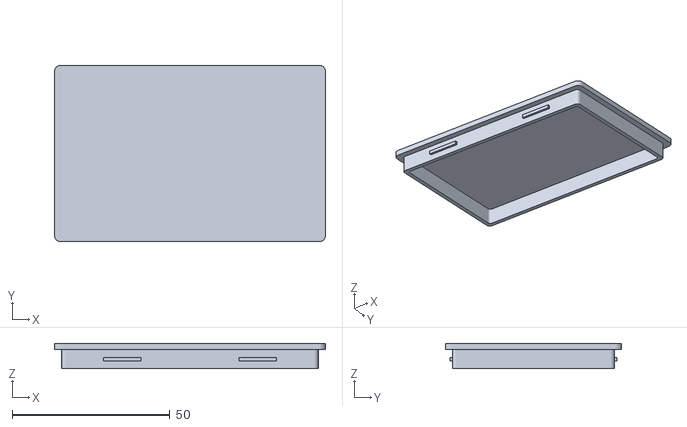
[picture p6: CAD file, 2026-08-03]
hardware/electronics_lid_snap.stl
86.0 x 56.0 x 8.00

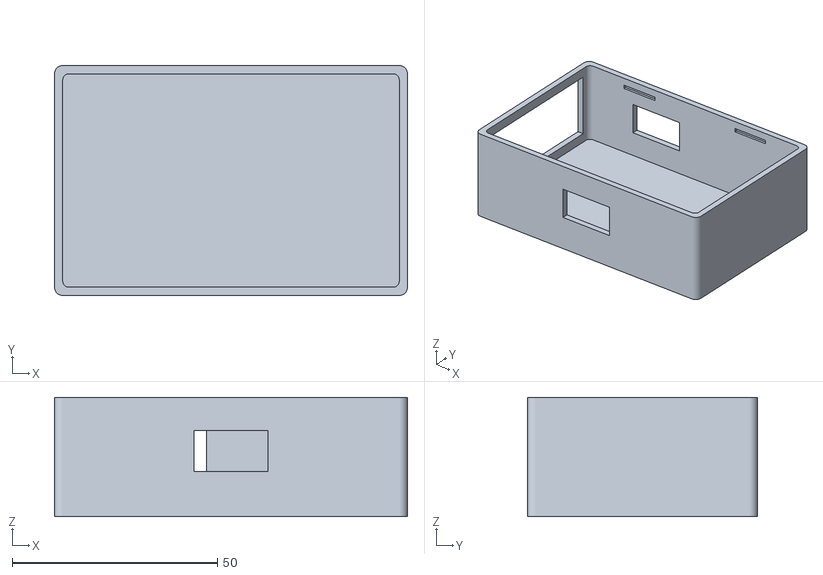
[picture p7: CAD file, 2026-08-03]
hardware/electronics_box_snap.stl
86.0 x 56.0 x 29.0

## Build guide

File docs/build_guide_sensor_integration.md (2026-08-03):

# Build Guide — Adding the Research Sensors to Your Device

This adds the **EMG (BioAmp EXG Pill)**, **IMU (MPU-6050)**, and optional **pulse sensor (MAX30100)** to your existing bow-grip device, without disturbing the FSR + motor circuit that already works.

**Golden rule for this build:** don't rewire what already works. Your FSRs and motor stay exactly as they are. You are *adding* three sensors, not rebuilding.

---

## Read this before touching anything

Three constraints that shape every step below:

1. **Fix the power blocker first.** Your known issue (ESP32 dropping out when seated in the perfboard) must be solved *before* you add sensors. Adding three more things to the 3.3V rail will only make a marginal power path worse, and you'll waste hours chasing "the new sensor broke it" when really the rail was already weak. Get the bare device booting reliably on battery first.

2. **All analog inputs must be on ADC1 pins.** The ESP32's ADC2 pins stop working for analog reads when WiFi/Bluetooth is active — and you stream over Bluetooth. So FSR1, FSR2, **and** the new EMG signal must all sit on **ADC1** pins: GPIO 32, 33, 34, 35, 36, or 39. Before you start, confirm your two FSRs are already on ADC1 pins. If either FSR is on an ADC2 pin (0, 2, 4, 12–15, 25–27), move it now, or its readings will be garbage once Bluetooth is on.

3. **Power everything from the 3.3V rail, not 5V.** Your device runs LiPo → TP4056 → 3.3V; there is no 5V rail on battery. This actually makes the EMG wiring *safer* (see Step 2).

---

## The pin map

**Keep as-is (already on your board):**
- FSR1 → existing ADC1 pin
- FSR2 → existing ADC1 pin
- Vibration motor → existing pin via your MOSFET driver
- 3.3V rail and GND → as wired

**Add (new):**
| New part | Pin on ESP32 | Notes |
|---|---|---|
| BioAmp **OUT** (EMG signal) | a free **ADC1** pin (e.g. GPIO32 or 33) | analog input |
| BioAmp **VCC** | **3.3V** | NOT 5V — see Step 2 |
| BioAmp **GND** | GND | |
| MPU-6050 **SDA** | **GPIO21** | I²C data |
| MPU-6050 **SCL** | **GPIO22** | I²C clock |
| MPU-6050 **VCC** | 3.3V | |
| MPU-6050 **GND** | GND | |
| MAX30100 SDA/SCL (optional) | GPIO21 / GPIO22 | shares the I²C bus |
| MAX30100 VIN / GND (optional) | 3.3V / GND | |

GPIO21/22 are the ESP32's default I²C pins — confirmed standard across ESP32 references.

---

## Step 0 — Confirm the baseline

Power the existing device on battery. Verify: it boots and stays on, both FSRs read sensible values, and the motor buzzes. If anything here is flaky, stop and fix it before adding sensors. You want a known-good starting point so any new problem is clearly caused by the new part.

---

## Step 1 — Add the IMU (MPU-6050) on the bow

This is the easiest sensor, so do it first to get the I²C bus working.

1. Mount the MPU-6050 on the **bow** (near the frog, with the FSRs) — it must be on the bow because it senses *bow motion*, which is your anticipation signal.
2. Wire it: **VCC → 3.3V, GND → GND, SDA → GPIO21, SCL → GPIO22.** The GY-521 module has an onboard regulator and pull-up resistors, so 3.3V power is the safe, standard choice.
3. These four lines now have to travel from the bow to the wrist unit. VCC and GND can share the existing 4-pin bow connector (the FSRs already carry power/ground across it). SDA and SCL go through your **new 2-pin connector**.
4. **Test before continuing.** Upload an I²C scanner sketch. The MPU-6050 should appear at address **0x68**. If it doesn't show up, check SDA/SCL aren't swapped, and if still nothing, add 10kΩ pull-up resistors from SDA→3.3V and SCL→3.3V (most GY-521 boards already have these, but a long bow cable can need them).

Do not move on until the scanner sees 0x68.

---

## Step 2 — Add the EMG (BioAmp EXG Pill) — the careful one

**Why this step needs care:** the ESP32's ADC can only safely accept up to **3.3V** on an input pin. The BioAmp's OUT signal is centered at half its supply voltage and swings around it. If you powered the BioAmp at **5V**, its output could swing well above 3.3V and **stress or damage your ESP32's ADC pin**. The official Upside Down Labs ESP32 example handles this by powering at 5V *and* adding a 2.2kΩ + 1kΩ voltage divider on the OUT line to scale it down.

**Your simpler, safe path:** because your device only has a 3.3V rail, **power the BioAmp from 3.3V**. At a 3.3V supply, the output physically cannot exceed 3.3V, so it's safe to wire OUT directly to the ESP32 ADC with **no divider needed**. This is both safe and fewer parts — it works out neatly for your battery design.

Wiring:
1. **Double-check VCC and GND orientation before powering.** The datasheet has a hard warning: if the power pins are swapped, the board is destroyed permanently. Verify against the silkscreen.
2. BioAmp **VCC → 3.3V**, **GND → GND**.
3. BioAmp **OUT → a free ADC1 pin** (e.g. GPIO32).
4. Plug the included **BioAmp cable** into the board's JST socket, and snap **3 gel electrodes** onto the cable.
5. Electrode placement (from the datasheet, for EMG): the two signal electrodes (IN+ / IN−) go **along the forearm extensor muscle belly**, and the reference (REF) goes on a **bony spot** like the elbow or wrist bone.
6. Optional but worth it: wipe the skin clean (or use prep gel) before sticking electrodes — cleaner signal.

**Note on board version:** if your specific board is the **2025 edition**, it's natively 3.3V-compatible and this is all standard. If it's an **older (pre-2025) version**, powering at 3.3V is still electrically safe; if the EMG signal comes out weak, that's a software gain/normalization fix, not a safety problem — do not "fix" it by jumping to 5V without adding the divider.

**Test:** with the device running, open the Arduino Serial Plotter (or Upside Down Labs' Chords Web) and watch the EMG channel while you clench your forearm. You should see the trace jump with muscle activation. If it works, this sensor is done.

---

## Step 3 — (Optional) Add the pulse sensor (MAX30100)

Be warned: **this is the sensor most likely to fight you.** The common red/purple MAX30100 breakout boards are known to be finicky on the ESP32's 3.3V I²C bus (their onboard pull-ups are referenced to 1.8V), and there are documented cases of the MAX30100 returning zeros while an MPU-6050 on the *same* bus works fine. Treat it as a nice-to-have, not a blocker.

1. Wire it onto the **same I²C bus**: SDA → GPIO21, SCL → GPIO22, VIN → 3.3V, GND → GND. It lives on the **wrist unit** (it reads your pulse at the wrist), so no bow connector needed.
2. Run the I²C scanner again. The MAX30100 should appear at **0x57** (alongside the MPU-6050 at 0x68 — different addresses, so they coexist).
3. If it returns 0x57 but gives zero data, that's the known pull-up issue. Options: try a dedicated MAX30100 library's known ESP32 workaround, modify the board's pull-ups, or simply **drop this sensor** — your core project (EMG + IMU + FSR) does not depend on it.

Don't let this sensor delay the rest of the build. If it misbehaves for more than an hour, set it aside.

---

## Step 4 — The bow connector

Your bow now carries six lines to the wrist: power, ground, FSR1, FSR2 (existing 4-pin), plus SDA and SCL for the IMU (new 2-pin). Confirm the 2-pin connector is seated and that you didn't mix pitches within one connector (housing and pins must match). The IMU's power/ground tap off the existing 4-pin lines on the bow side, so the 2-pin only carries the two I²C signals.

---

## Step 5 — Firmware changes

Your firmware grows from "read 2 analog + drive motor" to "read 3 analog + read IMU + stream + switch modes." Concretely:

1. **Read three analog channels** now: FSR1, FSR2, and EMG (the new ADC1 pin).
2. **Read the IMU** over I²C — initialize `Wire.begin(21, 22)`, talk to address 0x68. Use a library like `Adafruit_MPU6050` or `MPU6050` to pull the 6 values (accel x/y/z, gyro x/y/z).
3. **(Optional) read the MAX30100** via a MAX30100 library if you kept it.
4. **Timestamp every sample** with `millis()` and **stream the whole row over Bluetooth** (BluetoothSerial) to your laptop, which logs CSV. One timestamp per row is what keeps grip and motion aligned — that shared clock *is* your sensor sync.
5. **Add a mode switch:** RECORD (motor off, logging on — for data collection) vs FEEDBACK (motor on, feedback curve runs — for the intervention phase).
6. **Fix the motor curve bug** before you ever use FEEDBACK mode. Your `exponentialMap()` currently collapses to a constant output of 60 because every gradient term is multiplied by `(60 − MIN_MOTOR)`, and `MIN_MOTOR` is 60, so that's × 0. The motor never ramps and never reaches MAX_MOTOR. Decide your real zone ceilings and replace those `60` literals before relying on feedback.

**Keep EMG and motor apart in time.** The vibration motor is electrically noisy; recording microvolt-level EMG while the motor buzzes on the same rail will pollute the signal. This is fine in practice because your data-collection phase runs motor-OFF anyway — just be aware of it during the feedback phase.

---

## Step 6 — Validation checklist (do these in order)

- [ ] Bare device boots and stays powered on battery (power blocker resolved)
- [ ] Both FSRs confirmed on ADC1 pins
- [ ] I²C scanner sees MPU-6050 at 0x68
- [ ] EMG trace responds to forearm clench in the Serial Plotter
- [ ] (Optional) MAX30100 at 0x57 returning real data — or consciously dropped
- [ ] Bluetooth stream logs a clean CSV row: timestamp, FSR1, FSR2, EMG, 6× IMU
- [ ] Motor curve bug fixed before enabling FEEDBACK mode

---

## Cross-reference notes (what changed vs. earlier plans, and why)

- **FSR + motor pins:** I did not re-specify your exact existing FSR/motor GPIO numbers, because the safe move is to leave the working circuit untouched — verify only that the FSRs sit on ADC1 pins.
- **BioAmp power:** earlier we said "power everything off 3.3V" — validated and correct, and it turns out to be the *safety-critical* choice here (it's what lets you skip the voltage divider the official 5V wiring would otherwise require).
- **IMU on the bow:** unchanged and essential — it's the bow-motion/anticipation signal for the prediction (B) work.
- **MAX30100:** confirmed as the weakest link of the three; kept optional, exactly as we'd flagged.
- **2-pin connector:** still only needed because the IMU is on the bow.

*Validated against: the BioAmp EXG Pill datasheet, the Upside Down Labs / Crowd Supply ESP32 integration guide, and standard ESP32 MPU-6050 / MAX30100 references.*

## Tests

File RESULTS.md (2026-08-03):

# Results

Single-subject (n = 1) study of a haptic bow-grip biofeedback wearable. Pre-registered A-B-A-B reversal design with a transfer test. All analyses follow the pre-registration in `docs/pre_registration.md` except where explicitly noted.

---

## 1. Data collected

| Phase | Feedback | Sessions | Status |
|---|---|---|---|
| A1 baseline | off | 5 | analysed |
| B1 intervention | on | 5 | analysed |
| A2 withdrawal (attempt 1) | off | 5 | excluded — EMG electrodes omitted; grip data retained for trend analysis |
| A2 withdrawal (attempt 2) | off | 5 | excluded — different bow altered thumb contact geometry |
| A2 withdrawal (attempt 3) | off | 5 | analysed |
| B2 re-intervention | on | 5 | analysed |
| Transfer | off | 3 | analysed |

33 playing sessions in total; 23 used for phase comparisons. All 33 are treated as practice exposure in the trend analysis, since the participant was playing in every one.

**Sessions were not spaced across days.** Each phase was recorded within a single afternoon, sessions 13–21 minutes apart: A1 on 08 Jul, B1 on 09 Jul, A2 on 23 Jul, B2 on 25 Jul, transfer on 28 Jul. There are therefore **5 testing days, and phase is perfectly confounded with day**. This has direct consequences for the statistics below and is detailed in [`docs/DEVIATIONS.md`](docs/DEVIATIONS.md).

Data quality after the baud-rate correction (session 11 onward) was 0.00% row rejection at a sustained 100 Hz. Earlier sessions ran at 21–50 Hz effective rate with intermittent serial corruption; the strict-validation logger discards affected rows.

---

## 2. Primary outcome

**Definition (pre-registered):** percentage of playing time during which grip force exceeds the participant's personal overgrip threshold.

**Threshold:** 1301 raw ADC units — the 85th percentile of the pooled A1 baseline grip distribution (n = 70,025 samples). Per-session A1 85th percentiles were tightly clustered (1171–1424), indicating a stable baseline. Fixed for the remainder of the study.

**Segmentation:** the bowing period is isolated from IMU gyroscope magnitude (2 s rolling mean > 25 °/s, longest contiguous block). This excludes the MVC clenches and maximum grip presses, which are deliberate maximal squeezes and would otherwise inflate the outcome. Whole-file analyses reported earlier in development were biased upward for this reason.

### Phase results

| Phase | Feedback | Mean | Median | Range |
|---|---|---|---|---|
| A1 baseline | off | **12.57%** | 8.94 | 6.02 – 23.25 |
| B1 intervention | on | **6.22%** | 4.98 | 3.71 – 9.17 |
| A2 withdrawal | off | **1.37%** | 1.55 | 0.13 – 2.82 |
| B2 re-intervention | on | **1.30%** | 1.06 | 0.70 – 2.33 |
| Transfer | off | **0.55%** | 0.47 | 0.40 – 0.80 |

Transfer sessions used three different untrained pieces, one per session, rather than one piece repeated: Albinoni *Allegro assai* (bars 1–20), Mel Bonis *Allegretto non troppo* (bars 1–20), and Florence Price *Elfentanz* (bars 1–38). Per-session overgrip was 0.40%, 0.80%, and 0.47% respectively. Session 1 was played at a slower tempo, which reduces bow-change frequency and therefore overgrip opportunity; it is the lowest of the three but not by a margin that changes the conclusion. All three fall far below every baseline session regardless.

### Effect sizes versus baseline

| Contrast | NAP | Tau | Nominal *p* |
|---|---|---|---|
| A1 vs B1 | 76.0% | +0.52 | 0.111 |
| A1 vs A2 | **100.0%** | +1.00 | 0.004 |
| A1 vs B2 | **100.0%** | +1.00 | 0.004 |
| A1 vs Transfer | **100.0%** | +1.00 | 0.018 |

Every session in A2, B2, and the transfer test falls below every baseline session. Complete non-overlap is among the strongest criteria available in single-case visual analysis, and the magnitude of separation is not in doubt.

**The *p* values above are reported for completeness but should not be relied on.** They treat five same-day recordings as independent replicates. Because every phase was collected within a single afternoon, the effective sample is **one observation per condition**, and no inferential test is appropriate. These comparisons are **descriptive**.

Partial mitigation: within-day trends are flat (log-overgrip regressed on within-day session order gives *p* = 0.61, 0.87, 0.92, 0.42, 0.20 for A1, B1, A2, B2, transfer). The same-day sessions behave as repeated measurements of a stable daily state rather than as a within-day learning curve, which is what makes the day-level means meaningful.

---

## 3. Causal analysis — null result

The reversal design was intended to attribute the improvement to the haptic feedback. It does not.

**Withdrawal produced no rebound.** Removing feedback after B1 (6.22%) was followed by a *further* decrease in A2 (1.37%), not a return toward baseline. Reinstating feedback in B2 changed nothing (1.30%; A2 vs B2 *p* = 1.000).

**The data are described by a monotonic trend in practice exposure.** Regressing log overgrip on session index across all 33 playing sessions:

- slope = −0.093 per session (≈ **8.9% relative decline per session**)
- *r* = −0.70, *p* = 5.8 × 10⁻⁶
- R² = 0.490

**Feedback status adds nothing to that model.** Including a feedback-on indicator:

- coefficient = +0.108 (wrong sign for a beneficial effect)
- *F* = 0.09, *p* = **0.765**
- R² rises from 0.490 to 0.492

**The first feedback exposure was not distinguishable from baseline** (A1 vs B1, NAP 76%, *p* = 0.111) — precisely where a causal effect should be most visible.

**A 14-day unmeasured gap contains the largest single drop.** B1 was recorded on 09 Jul and A2 on 23 Jul. Overgrip fell from 6.22% to 1.37% across that interval — a 78% relative reduction — with no data collected and ordinary practice presumably continuing. The decline also fits elapsed calendar time better than session count (*r* = −0.858, *p* = 1.7 × 10⁻⁷ versus *r* = −0.809, *p* = 3.0 × 10⁻⁶), consistent with a between-day consolidation process rather than within-session correction. Whatever occurred during those two weeks is unmeasured and is the most plausible single driver of the headline reduction.

### Interpretation

Something in this protocol produced a large, durable reduction in bow-grip overtension. The design cannot identify what. Three explanations remain equally consistent with the data:

1. **Motor practice** — 33 repetitions of the same two scales.
2. **Measurement reactivity** — knowing that grip is being recorded.
3. **Proprioceptive attention** — a sensor physically pressed against the thumb makes grip salient, feedback or not.
4. **Unmeasured activity during the 14-day gap** between B1 and A2, which brackets the largest observed change.

The haptic feedback specifically is *not* supported as the causal agent. Claims in this repository are limited accordingly.

---

## 4. Secondary outcome: EMG

EMG activation (mean absolute deviation from session median, during the bowing period) declined within each electrode-setup era:

- A1 → B1: 1525 → 404
- A2 → B2 → transfer: 170 → 97 → 124

A roughly threefold discontinuity coincides with the electrode re-application between B1 and A2, so absolute levels either side of that boundary are not comparable. The within-era declines corroborate the grip findings directionally but cannot be pooled.

Because sampling ran at 21–100 Hz, EMG here is an **amplitude/envelope** measure. Spectral fatigue analysis (median-frequency shift) requires ~1000 Hz sampling and is not possible with this dataset.

---

## 5. Prediction of overgrip onset

**Task.** At each moment during playing, predict whether an overgrip onset will occur within a target window ahead. Onsets are upward crossings of the 1301 threshold sustained ≥100 ms: **297 onsets across the five A1 baseline sessions.**

**Method.** Sessions resampled to a uniform 50 Hz grid. Candidate moments are restricted to the bowing period, currently below threshold, and outside a 0.5 s refractory window after any prior above-threshold sample. 21 features from a causal lookback window: grip level, rolling means (200/500/1000 ms), rolling standard deviations, slopes, deltas, headroom to threshold, gyroscope magnitude statistics, accelerometer variability, EMG deviation. Classifier: histogram gradient-boosted trees. Validation: **leave-one-session-out**.

### Lead-time curve

| Window | Prevalence | Average precision | Lift | ROC-AUC | Grip-level baseline |
|---|---|---|---|---|---|
| 0–200 ms | 1.22% | 0.260 | 21.4× | 0.902 | 0.143 |
| 100–300 ms | 1.25% | 0.114 | 9.2× | 0.815 | 0.056 |
| **200–400 ms** (pre-registered) | 1.26% | **0.093** | **7.4×** | **0.859** | 0.045 |
| 300–500 ms | 1.28% | 0.106 | 8.2× | 0.861 | 0.050 |
| 500–700 ms | 1.33% | 0.079 | 5.9× | 0.823 | 0.072 |
| 800–1000 ms | 1.52% | 0.072 | 4.7× | 0.796 | 0.054 |

The model consistently beats both chance and a grip-level-only baseline. Performance falls sharply past 200 ms and then plateaus — most of the predictable signal lies in the final fifth of a second before onset.

### Event-level performance

Constraining to ≤2 false alarms per minute, per-fold recall of onset events was 3.1%, 0%, 100%, 0%, 2.6%. The mean of 21.2% is carried entirely by one fold containing only six events; the median is ~3%. **A practical warning system is not achievable at this performance level.**

### Feature importance

Permutation importance is dominated by grip-derived features: 1 s rolling maximum, 500 ms and 200 ms standard deviations, rolling means. **IMU bow-motion features contribute negligibly.**

This reframes the result. The model is not anticipating overgrip from independent bow kinematics; it is recognising a squeeze that has already begun to develop. The honest description is *early detection*, not *prediction*.

---

## 6. Sensor validity check

The proportion of samples reading exactly zero rose across the study (≈6% early, 57% in the final transfer session), and median grip fell from ~900 to 0. Two explanations were possible: genuine relaxation below the FSR's activation floor, or progressive contact degradation.

Two checks were run:

1. **Maximum grip-press peaks** at the start of each session were stable throughout: A1 2824–3185, B1 2511–2839, A2 2803–3300, B2 2839–3193, transfer 2799–3202. High-force response did not drift.
2. **Comparison against a fresh FSR** at matched low forces showed the original sensor activating at *lower* force than the new unit — its low-force sensitivity had not degraded.

Sensor wear is therefore rejected as the explanation. The zeros reflect genuine light contact falling below the sensor's activation floor. The consequence is that grip data is **floor-censored** in later sessions: median and mean grip are directional only, while the overgrip metric — which counts samples above a high threshold — is unaffected.

---

## 7. Summary of claims

**Supported:**
- A low-cost wearable can continuously measure bow-grip force, forearm EMG, and bow motion during unmodified violin practice.
- Over 33 sessions, overgrip fell ~95%, persisted without feedback, and generalised to untrained repertoire, with complete non-overlap between baseline and all later phases (*p* = 0.004).
- Overgrip onset carries statistically detectable precursor signal a few hundred milliseconds ahead (ROC-AUC 0.86 at 200–400 ms), about twice a naive grip-level baseline.

**Not supported:**
- That the haptic feedback caused the improvement (*p* = 0.77 for feedback beyond trend).
- That the prediction model is deployable (≈3% median event recall at a tolerable alarm rate).
- Any generalisation beyond this individual.

---

## 8. Session spacing — a limitation affecting all phase statistics

All 33 sessions fell on **7 calendar dates**, with each phase's five sessions run consecutively within roughly 90 minutes on a single day (see `data/README.md` for the schedule).

Consequences:

- **Sessions within a phase are not independent.** NAP, Tau, and Mann-Whitney statistics above treat them as independent observations, which they are not. The effective sample size per phase is nearer 1 than 5, and the reported *p*-values should be read as descriptive rather than inferential.
- **Phase is perfectly confounded with date.** Any day-specific factor — electrode placement, ambient conditions, how the participant felt — is indistinguishable from phase.
- **Within-day fatigue is uncontrolled**, though it would work against the observed effect rather than producing it.

Re-running the trend against **elapsed calendar time** rather than session index gives *r* = −0.639, *p* = 6.2 × 10⁻⁵, R² = 0.409 — the same conclusion as the session-index model (*r* = −0.700, R² = 0.490), with time explaining slightly less variance than cumulative sessions. Both support a practice-driven decline; neither supports the feedback.

A replication should space sessions across separate days.

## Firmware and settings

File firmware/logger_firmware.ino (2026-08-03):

/*
 * Bow-Grip Biofeedback Wearable - logging + feedback firmware
 *
 * Samples thumb force (FSR), forearm EMG, and hand IMU on a fixed schedule
 * and streams CSV over USB serial at 115200 baud:
 *
 *     t_ms,fsr1,fsr2,emg,ax,ay,az,gx,gy,gz,mode
 *
 * Modes, switched by sending a single character over serial:
 *     'R'  record   - motor disabled (baseline / withdrawal / transfer)
 *     'F'  feedback - motor driven by grip above threshold (intervention)
 *
 * IMPORTANT: GRIP_THRESH and ZONE2_START below must be derived from the
 * individual wearer's own baseline data. The values here are the 85th and
 * 95th percentiles of one participant's baseline grip distribution and are
 * meaningless for anyone else.
 *
 * Requires ESP32 Arduino core 3.x (uses ledcAttach / pin-addressed ledcWrite)
 * and the MPU6050_tockn library (many cheap MPU-6050 modules are clones that
 * fail to initialise with other drivers; note it reports accel in g, not m/s^2).
 *
 * Keep the board still at power-up: the gyroscope calibrates on boot.
 *
 * Licence: MIT
 */

#include <Wire.h>
#include <MPU6050_tockn.h>

// ---- Pin map (all analog inputs on ADC1, safe with radio active) ----
const int FSR1_PIN  = 35;   // thumb force sensor - primary grip signal
const int FSR2_PIN  = 34;   // second FSR channel (unused in this build)
const int EMG_PIN   = 32;   // BioAmp EXG Pill output
const int SDA_PIN   = 21;   // IMU I2C
const int SCL_PIN   = 22;
const int MOTOR_PIN = 25;   // MOSFET gate

const int MOTOR_FREQ = 20000;   // above audible range
const int MOTOR_RES  = 8;       // 8-bit duty (0-255)

MPU6050 mpu(Wire);
bool imuOK = false;
char mode = 'R';                // default to record: motor off

// ---- Feedback curve - PERSONALISE THESE ----
const int GRIP_THRESH = 1301;   // 85th percentile of wearer's baseline grip
const int ZONE2_START = 1584;   // 95th percentile - steeper ramp above this
const int MIN_MOTOR   = 60;     // lowest perceptible duty
const int ZONE1_MAX   = 110;
const int MAX_MOTOR   = 220;

// Two-zone proportional ramp: gentle nudge just above threshold,
// stronger response for pronounced overgrip.
int gripToMotor(int g) {
  if (g <= GRIP_THRESH) return 0;
  if (g <= ZONE2_START) {
    float t = (float)(g - GRIP_THRESH) / (ZONE2_START - GRIP_THRESH);
    return (int)(MIN_MOTOR + t * (ZONE1_MAX - MIN_MOTOR));
  }
  float t = (float)(g - ZONE2_START) / (4095 - ZONE2_START);
  int d = (int)(ZONE1_MAX + t * (MAX_MOTOR - ZONE1_MAX));
  return d > MAX_MOTOR ? MAX_MOTOR : d;
}

unsigned long lastSample = 0;
const unsigned long SAMPLE_US = 10000;   // 100 Hz target

void setup() {
  Serial.begin(115200);   // 230400 produced intermittent row corruption

  analogReadResolution(12);
  analogSetPinAttenuation(FSR1_PIN, ADC_11db);
  analogSetPinAttenuation(FSR2_PIN, ADC_11db);
  analogSetPinAttenuation(EMG_PIN,  ADC_11db);

  ledcAttach(MOTOR_PIN, MOTOR_FREQ, MOTOR_RES);
  ledcWrite(MOTOR_PIN, 0);

  Wire.begin(SDA_PIN, SCL_PIN);
  bool seen = false;
  for (byte a = 1; a < 127; a++) {
    Wire.beginTransmission(a);
    if (Wire.endTransmission() == 0 && a == 0x68) seen = true;
  }
  if (seen) {
    mpu.begin();
    mpu.calcGyroOffsets(false);
    imuOK = true;
  }

  Serial.println("# t_ms,fsr1,fsr2,emg,ax,ay,az,gx,gy,gz,mode");
}

void loop() {
  if (Serial.available()) {
    char c = Serial.read();
    if (c == 'R' || c == 'r') { mode = 'R'; ledcWrite(MOTOR_PIN, 0); }
    if (c == 'F' || c == 'f') { mode = 'F'; }
  }

  unsigned long now = micros();
  if (now - lastSample >= SAMPLE_US) {
    lastSample += SAMPLE_US;

    int f1 = analogRead(FSR1_PIN);
    int f2 = analogRead(FSR2_PIN);
    int e  = analogRead(EMG_PIN);

    float ax = 0, ay = 0, az = 0, gx = 0, gy = 0, gz = 0;
    if (imuOK) {
      mpu.update();
      ax = mpu.getAccX();  ay = mpu.getAccY();  az = mpu.getAccZ();
      gx = mpu.getGyroX(); gy = mpu.getGyroY(); gz = mpu.getGyroZ();
    }

    int grip = (f1 > f2) ? f1 : f2;
    ledcWrite(MOTOR_PIN, (mode == 'F') ? gripToMotor(grip) : 0);

    Serial.print(millis()); Serial.print(',');
    Serial.print(f1); Serial.print(','); Serial.print(f2); Serial.print(','); Serial.print(e); Serial.print(',');
    Serial.print(ax, 3); Serial.print(','); Serial.print(ay, 3); Serial.print(','); Serial.print(az, 3); Serial.print(',');
    Serial.print(gx, 2); Serial.print(','); Serial.print(gy, 2); Serial.print(','); Serial.print(gz, 2); Serial.print(',');
    Serial.println(mode);
  }
}

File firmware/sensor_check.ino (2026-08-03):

/*
 * Bench test: verifies all sensor channels and the motor before collection.
 * Prints averaged readings, pulses the motor, and flags common fault
 * signatures on the FSR channels.  Serial Monitor at 115200.
 *
 * Licence: MIT
 */
#include <Wire.h>
#include <MPU6050_tockn.h>

const int FSR1_PIN = 35, FSR2_PIN = 34, EMG_PIN = 32;
const int SDA_PIN = 21, SCL_PIN = 22, MOTOR_PIN = 25;
const int MOTOR_FREQ = 20000, MOTOR_RES = 8;

MPU6050 mpu(Wire);
bool imuOK = false;

void analyze(int pin, int &lo, int &hi, int &avg) {
  const int N = 200;
  long sum = 0; lo = 4095; hi = 0;
  for (int i = 0; i < N; i++) {
    int v = analogRead(pin);
    sum += v;
    if (v < lo) lo = v;
    if (v > hi) hi = v;
    delayMicroseconds(200);
  }
  avg = sum / N;
}

void setup() {
  Serial.begin(115200);
  analogReadResolution(12);
  analogSetPinAttenuation(FSR1_PIN, ADC_11db);
  analogSetPinAttenuation(FSR2_PIN, ADC_11db);
  analogSetPinAttenuation(EMG_PIN,  ADC_11db);
  ledcAttach(MOTOR_PIN, MOTOR_FREQ, MOTOR_RES);
  ledcWrite(MOTOR_PIN, 0);

  Wire.begin(SDA_PIN, SCL_PIN);
  Serial.println("Scanning I2C...");
  for (byte a = 1; a < 127; a++) {
    Wire.beginTransmission(a);
    if (Wire.endTransmission() == 0) {
      Serial.print("  device at 0x"); Serial.println(a, HEX);
      if (a == 0x68) imuOK = true;
    }
  }
  if (imuOK) { mpu.begin(); mpu.calcGyroOffsets(true); Serial.println("MPU6050 OK"); }
  else Serial.println("MPU6050 NOT FOUND - check D21/D22, power, ground");
}

void loop() {
  int l1, h1, a1, l2, h2, a2, le, he, ae;
  analyze(FSR1_PIN, l1, h1, a1);
  analyze(FSR2_PIN, l2, h2, a2);
  analyze(EMG_PIN,  le, he, ae);

  Serial.print("FSR1 avg="); Serial.print(a1);
  Serial.print(" spread="); Serial.print(h1 - l1);
  Serial.print(" | FSR2 avg="); Serial.print(a2);
  Serial.print(" spread="); Serial.print(h2 - l2);
  Serial.print(" | EMG avg="); Serial.print(ae);

  // fault signatures on the primary grip channel
  if (l1 == 0 && h1 >= 4090)  Serial.print("   <-- FSR1 jumping 0<->4095 (loose connection)");
  else if (a1 >= 4090)        Serial.print("   <-- FSR1 railed (floating: check divider)");
  else if (h1 - l1 > 300)     Serial.print("   <-- FSR1 noisy");

  if (imuOK) {
    mpu.update();
    Serial.print(" | accel ");
    Serial.print(mpu.getAccX(), 2); Serial.print("/");
    Serial.print(mpu.getAccY(), 2); Serial.print("/");
    Serial.print(mpu.getAccZ(), 2);
  }
  Serial.println();

  Serial.println(">>> motor ON 1s");
  ledcWrite(MOTOR_PIN, 180);
  delay(1000);
  ledcWrite(MOTOR_PIN, 0);
  delay(2000);
}
